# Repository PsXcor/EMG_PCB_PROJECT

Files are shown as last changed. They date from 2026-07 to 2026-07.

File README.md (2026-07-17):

# EMG PCB Project

A custom wearable electromyography (EMG) acquisition system built around the **Texas Instruments ADS1299-4** analog front end and the **Seeed Studio XIAO nRF52840**.

The project includes:

- A custom 4-layer KiCad PCB
- Arduino firmware for ADS1299 configuration and sampling
- Bluetooth Low Energy (BLE) data streaming
- A Python receiver for live plotting, diagnostics, and CSV recording
- Project-local KiCad symbols, footprints, and 3D models

> **Project status:** Active prototype development. The hardware, firmware, BLE protocol, and signal-processing workflow are still being tested and refined.

---

## Project Overview

The system measures small differential biopotential signals using the ADS1299-4, transfers samples to the XIAO nRF52840 over SPI, and sends the data wirelessly to a computer over BLE.

```text
Skin electrodes
      │
      ▼
Input protection and filtering
      │
      ▼
ADS1299-4 analog front end
      │  SPI + DRDY
      ▼
XIAO nRF52840
      │  Bluetooth Low Energy
      ▼
Python receiver
      ├── Live plot
      ├── Packet diagnostics
      └── CSV recording
```

> **Add image:** photo of the assembled PCB and battery-powered

---

## Current Capabilities

- Reads the ADS1299 device ID successfully
- Configures the ADS1299 through SPI
- Supports internal test-signal and input-short testing
- Samples at **250 samples per second**
- Currently focuses on **ADS1299 Channel 4**
- Decodes signed 24-bit two's-complement ADC samples
- Streams custom BLE notifications from the XIAO nRF52840
- Receives and plots samples in Python
- Optionally records received samples to CSV
- Tracks malformed, missing, duplicate, and out-of-order packets
- Includes project-local KiCad libraries for portability

Current development work includes:

- Reducing electrode-motion artifacts
- Investigating clipping during movement
- Improving the flexed-muscle signal-to-noise ratio
- real-time data processing
- Comparing operation with and without ADS1299 BIAS drive
- Refining packet reliability and receiver-side validation
- Developing a future Android application

---

## Repository Structure

```text
EMG_PCB_PROJECT/
├── firmware/
│   ├── emg.ble/
│   │   └── emg.ble.ino
│   └── test_ads_mcu_communication_preinstal/
│       └── test_ads_mcu_communication_preinstal.ino
│
├── python/
│   └── emg_project/
│       ├── emg_ble_receiver.py
│       ├── requirements.txt
│       └── .venv/                  
│
├── hardware/
│   └── kicad/
│       └── EMG_PCB/
│           ├── EMG_PCB.kicad_pro
│           ├── EMG_PCB.kicad_sch
│           ├── ADS1299_Section.kicad_sch
│           ├── MCU_Section.kicad_sch
│           ├── Power_Supplies.kicad_sch
│           ├── EMG_PCB.kicad_pcb
│           ├── fp-lib-table
│           ├── sym-lib-table
│           ├── lib/
│           │   ├── symbols/
│           │   ├── footprints/
│           │   └── 3d_models/
│           └── EMG_PCB_Manufacture/
│
├── .gitignore
├── .gitattributes
└── README.md
```

## Hardware

### Main Components

| Component | Purpose |
|---|---|
| ADS1299-4PAGR | Four-channel, 24-bit biopotential analog front end |
| XIAO nRF52840 | Microcontroller, SPI controller, and BLE radio |
| External 2.048 MHz clock | ADS1299 master clock |
| Li-ion battery | Portable isolated power source |
| Custom analog power supplies | Generate the required analog and digital rails |
| Input protection/filter network | Protects and filters electrode inputs |
| Electrode connector | Connects the measurement and reference electrodes |

### Main Power Rails

The PCB uses the following rails:

- `+2.5 V`
- `-2.5 V`
- `3.3 V`
- Li-ion battery input
- USB `VBUS` for development and charging

The ADS1299 analog supply and reference arrangement are implemented on the custom board. The XIAO nRF52840 provides the embedded processing and BLE connection.





---

## KiCad Design

Open the complete project using:

```text
hardware/kicad/EMG_PCB/EMG_PCB.kicad_pro
```

Do not normally open one of the child schematic files directly.

### Schematic Hierarchy

The root schematic is:

```text
EMG_PCB.kicad_sch
```

It references these hierarchical child sheets:

```text
ADS1299_Section.kicad_sch
MCU_Section.kicad_sch
Power_Supplies.kicad_sch
```

The child `.kicad_sch` files are not duplicates. Each file stores one hierarchical page used by the root schematic.

### Project-Local Libraries

Custom KiCad resources are stored in:

```text
hardware/kicad/EMG_PCB/lib/
```

This includes:

- Custom symbols
- Custom footprints
- STEP/STP 3D models
- Project library tables

Keeping these resources in the repository makes the project easier to open on another computer without losing custom parts.

### Manufacturing Files

The `EMG_PCB_Manufacture` folder contains generated Gerber and drill files. Snapshot of a specific manufactured board revision.

## Firmware

The firmware is currently developed in the Arduino IDE for the XIAO nRF52840; however, switching over to platformer.io and Cursor for serious development.

### Current Acquisition Configuration

The active configuration has included:

- 250 SPS output data rate
- Channel 4 enabled for acquisition
- Channels 1–3 powered down during single-channel testing
- 24-bit signed conversion data
- Internal square-wave test mode
- Input-short noise testing
- Optional normal electrode mode
- Experimental operation with ADS1299 BIAS disabled or enabled

Register settings may change as testing continues. The firmware source should be treated as the authoritative current configuration.

---

## BLE Data Receiver

The Python receiver is located at:

```text
python/emg_project/emg_ble_receiver.py
```

It scans for the BLE device:

```text
Nykin-EMG
```

The receiver decodes the custom BLE packet format implemented by the firmware and can:

- Plot samples live
- Print samples
- Record data to CSV
- Run for a fixed duration
- Operate without plotting
- Report packet and protocol statistics

## Development Roadmap

- [x] Design custom ADS1299/XIAO PCB
- [x] Assemble initial prototype
- [x] Verify main power rails
- [x] Read ADS1299 device ID
- [x] Capture internal test signal
- [x] Perform input-short noise testing
- [x] Stream samples over BLE
- [x] Plot and save data in Python
- [ ] Finalize safe electrode-mode register configuration
- [ ] Improve motion-artifact rejection
- [ ] Validate voltage scaling and gain calculations
- [ ] Add repeatable electrode-placement documentation
- [ ] Add digital filtering and signal-quality metrics
- [ ] Develop Android receiver application
- [ ] Complete a revised PCB based on prototype findings

---

## Author Nykin Leskiw

Developed as a personal electrical engineering and embedded-systems project

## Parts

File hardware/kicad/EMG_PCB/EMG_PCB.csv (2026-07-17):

Reference | Qty | Value | DNP | Exclude from BOM | Exclude from Board | Footprint | Datasheet
C1,C4,C5,C6,C8,C9,C10,C15,C17,C18,C21,C30,C32,C34,C36,C43,C44,C46 | 18 | 1uF |  |  |  | Capacitor_SMD:C_0603_1608Metric_Pad1.08x0.95mm_HandSolder | https://www.digikey.ca/en/products/detail/wec/GRM188R61E105KA12D/26462312
C2,C3,C7,C13,C20,C22,C24,C25,C27 | 9 | 10uF |  |  |  | Capacitor_SMD:C_0805_2012Metric_Pad1.18x1.45mm_HandSolder | https://www.digikey.ca/en/products/detail/kemet/C0805C106K8PACTU/1090830
C11 | 1 | 100uF |  |  |  | Capacitor_SMD:C_1210_3225Metric_Pad1.33x2.70mm_HandSolder | https://www.digikey.ca/en/products/detail/taiyo-yuden/LMK325BJ107MM-T/1646594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
C12,C14,C16,C19,C26,C29,C31,C38,C40,C41 | 10 | 0.1uF |  |  |  | Capacitor_SMD:C_0603_1608Metric_Pad1.08x0.95mm_HandSolder | https://www.digikey.ca/en/products/detail/kemet/C0603C104K5RAC7411/3317013
C23,C28,C35 | 3 | 2.2uF |  |  |  | Capacitor_SMD:C_0603_1608Metric_Pad1.08x0.95mm_HandSolder | https://www.digikey.ca/en/products/detail/murata-electronics/GRM185R60J225KE26D/702531
C33 | 1 | 0.01uF |  |  |  | Capacitor_SMD:C_0603_1608Metric_Pad1.08x0.95mm_HandSolder | https://www.digikey.ca/en/products/detail/kemet/C0603C103K5RAC7411/6873864
C37,C39 | 2 | 4700pF |  |  |  | Capacitor_SMD:C_0603_1608Metric_Pad1.08x0.95mm_HandSolder | https://www.digikey.ca/en/products/detail/yageo/CC0603KRX7R9BB472/302817
C42 | 1 | 1.5nF |  |  |  | Capacitor_SMD:C_0603_1608Metric_Pad1.08x0.95mm_HandSolder | https://www.digikey.ca/en/products/detail/kemet/C0603X152J4HACTU/8334437
D1 | 1 | LED |  |  |  | Diode_SMD:D_0603_1608Metric_Pad1.05x0.95mm_HandSolder | https://www.digikey.ca/en/products/detail/inolux/IN-S63AT5A/7604703
F1 | 1 | 500mA trip |  |  |  | Fuse:Fuse_0805_2012Metric_Pad1.15x1.40mm_HandSolder | https://www.digikey.ca/en/products/detail/bel-fuse-inc/0ZCK0050FF2E/4156141
H1,H2,H3 | 3 | MountingHole_Pad |  | Excluded from BOM |  | TestPoint:TestPoint_THTPad_D1.5mm_Drill0.7mm | ~
H4 | 1 | MountingHole_Pad |  | Excluded from BOM |  | ADS1299-4PAG:Untitled | ~
J1 | 1 | Conn_01x04 |  |  |  | Molex_connector:MOLEX_874370443 | https://www.digikey.ca/en/products/detail/molex/0874370443/717642?s=N4IgTCBcDaIAwA4DsAWAzEuL0gLoF8g
J2 | 1 | USB_C_Receptacle_PowerOnly_6P |  |  |  | Connector_USB:USB_C_Receptacle_HRO_TYPE-C-31-M-17 | https://www.digikey.ca/en/products/detail/gct/USB4125-GF-A-0190/14559038
J3 | 1 | Conn_01x03_Pin |  |  |  | Connector_PinHeader_2.54mm:PinHeader_1x03_P2.54mm_Vertical | ~
L1,L2,L3,L4 | 4 | 3.3 |  |  |  | Inductor_SMD:L_0805_2012Metric_Pad1.05x1.20mm_HandSolder | https://www.digikey.ca/en/products/detail/tdk/MLZ2012A3R3WT000/2465152
OSC2 | 1 | HC735-2.048MHZ |  |  |  | Oscillator:Oscillator_SMD_Abracon_ASE-4Pin_3.2x2.5mm_HandSoldering | https://www.digikey.ca/en/products/detail/cts-frequency-controls/632L3I002M04800/5228155
R1,R6 | 2 | 4.99k |  |  |  | Resistor_SMD:R_0603_1608Metric_Pad0.98x0.95mm_HandSolder | https://www.digikey.ca/en/products/detail/yageo/RC0603FR-074K99L/727219
R2 | 1 | 1M |  |  |  | Resistor_SMD:R_0603_1608Metric_Pad0.98x0.95mm_HandSolder | https://www.digikey.ca/en/products/detail/yageo/RC0603FR-071ML/726844
R3,R4,R8,R9,R10,R11 | 6 | 10k |  |  |  | Resistor_SMD:R_0603_1608Metric_Pad0.98x0.95mm_HandSolder | https://www.digikey.ca/en/products/detail/yageo/RC0603FR-0710KL/726880
R5,R12,R16 | 3 | 0k |  |  |  | Resistor_SMD:R_0603_1608Metric_Pad0.98x0.95mm_HandSolder | https://www.digikey.ca/en/products/detail/yageo/RC0603JR-070RL/726675
R7 | 1 | 1k |  |  |  | Resistor_SMD:R_0603_1608Metric_Pad0.98x0.95mm_HandSolder | https://www.digikey.ca/en/products/detail/stackpole-electronics-inc/RMCF0603FT1K00/1761077
R13 | 1 | 100k |  |  |  | Resistor_SMD:R_0603_1608Metric_Pad0.98x0.95mm_HandSolder | https://www.digikey.ca/en/products/detail/yageo/RC0603FR-07100KL/726889
R14 | 1 | 200k |  |  |  | Resistor_SMD:R_0603_1608Metric_Pad0.98x0.95mm_HandSolder | https://www.digikey.ca/en/products/detail/susumu/RG1608P-204-B-T5/1240508
R15 | 1 | 47k |  |  |  | Resistor_SMD:R_0603_1608Metric_Pad0.98x0.95mm_HandSolder | https://www.digikey.ca/en/products/detail/yageo/RC0603FR-0747KL/727253
R17,R18 | 2 | 5.1k |  |  |  | Resistor_SMD:R_0201_0603Metric_Pad0.64x0.40mm_HandSolder | https://www.digikey.ca/en/products/detail/yageo/RC0603FR-075K1L/727268
SW1 | 1 | SW_SPDT |  |  |  | ADS1299-4PAG:MHSS1105 | https://www.digikey.ca/en/products/detail/apem-inc/MHSS1105/1949465
TP1,TP5,TP6,TP10 | 4 | TestPoint |  | Excluded from BOM |  | TestPoint:TestPoint_Pad_D4.0mm | ~
TP2,TP3,TP4,TP7 | 4 | TestPoint |  | Excluded from BOM |  | TestPoint:TestPoint_Pad_D2.5mm | ~
U1 | 1 | 102010448 |  |  |  | XIAO_nRF52840:MODULE_102010448 | https://www.digikey.ca/en/products/detail/seeed-technology-co-ltd/102010448/16652893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
U2 | 1 | TPS60403DBV |  |  |  | Package_TO_SOT_SMD:SOT-23-5 | https://www.ti.com/lit/ds/symlink/tps60401.pdf
U3 | 1 | ADS1299-4PAGR |  |  |  | ADS1299-4PAG:QFP50P1200X1200X120-64N | https://www.ti.com/lit/ds/symlink/ads1299-4.pdf?HQS=dis-dk-null-digikeymode-dsf-pf-null-wwe&ts=1773509797872
U4 | 1 | TPS72325DBV |  |  |  | Package_TO_SOT_SMD:SOT-23-5 | https://www.ti.com/lit/ds/symlink/tps723.pdf
U5 | 1 | TPS73225DBVT |  |  |  | Package_TO_SOT_SMD:SOT-23-5 | https://www.digikey.ca/en/products/detail/texas-instruments/TPS73225DBVT/604395
U6 | 1 | TPS7A2033 |  |  |  | Package_TO_SOT_SMD:SOT-23-5 | https://www.digikey.ca/en/products/detail/texas-instruments/TPS7A2033PDBVR/13566866
U7,U10 | 2 | TPD2E001DZDR |  |  |  | Package_TO_SOT_SMD:SOT-143_Handsoldering | https://www.digikey.ca/en/products/detail/texas-instruments/TPD2E001DZDR/1907454
U9 | 1 | USBLC6-2SC6 |  |  |  | Package_TO_SOT_SMD:SOT-23-6 | https://www.st.com/resource/en/datasheet/usblc6-2.pdf

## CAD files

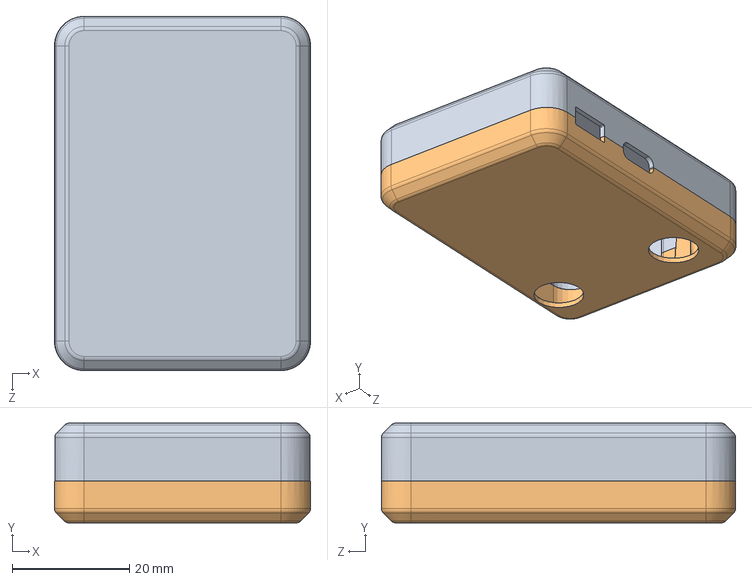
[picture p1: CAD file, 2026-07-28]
Mechanical/PCB_Case/case_asm.SLDASM
43.6 x 17.0 x 60.3 mm
enclosure_bottom
enclosure_top

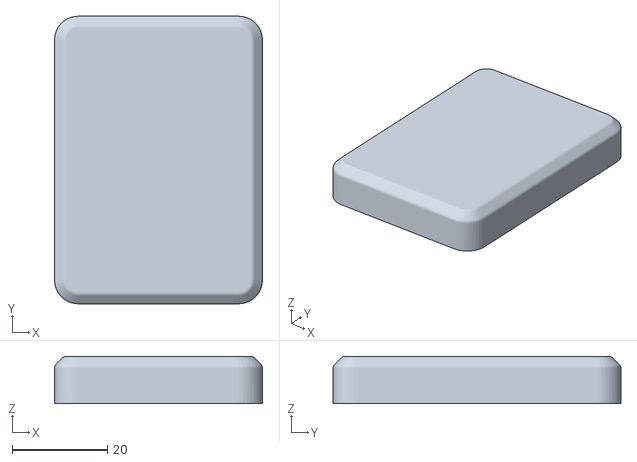
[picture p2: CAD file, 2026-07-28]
Mechanical/PCB_Case/STL_files/Print attempt1/enclosure_top.STL
43.6 x 60.3 x 9.90

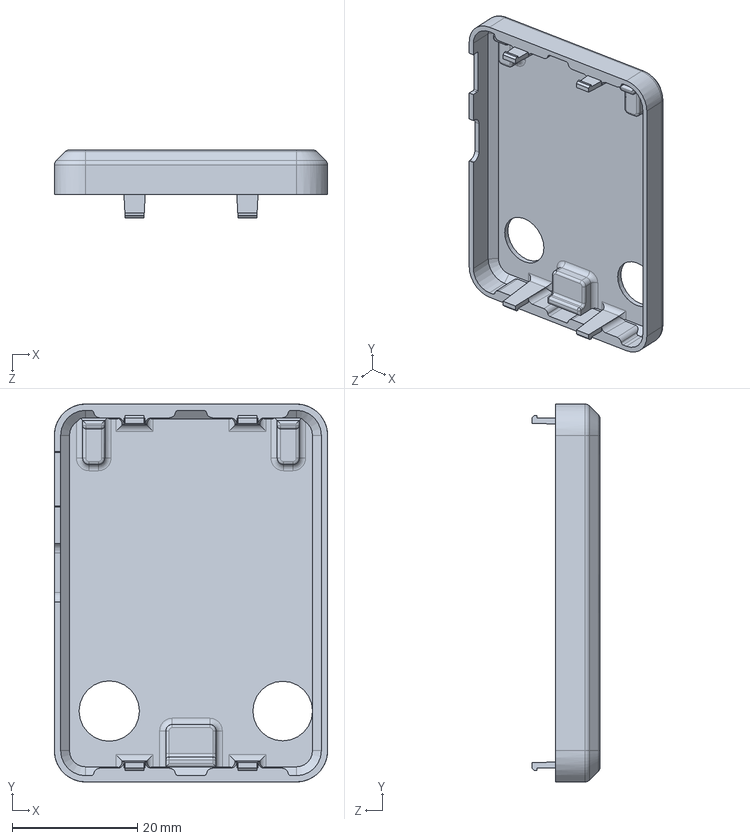
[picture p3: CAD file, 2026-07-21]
Mechanical/PCB_Case/enclosure_bottom.SLDPRT
43.6 x 60.3 x 10.9 mm

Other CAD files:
Mechanical/PCB_Case/STL_files/Print attempt1/enclosure_bottom.STL
Mechanical/PCB_Case/enclosure_master.SLDPRT
Mechanical/PCB_Case/enclosure_top.SLDPRT

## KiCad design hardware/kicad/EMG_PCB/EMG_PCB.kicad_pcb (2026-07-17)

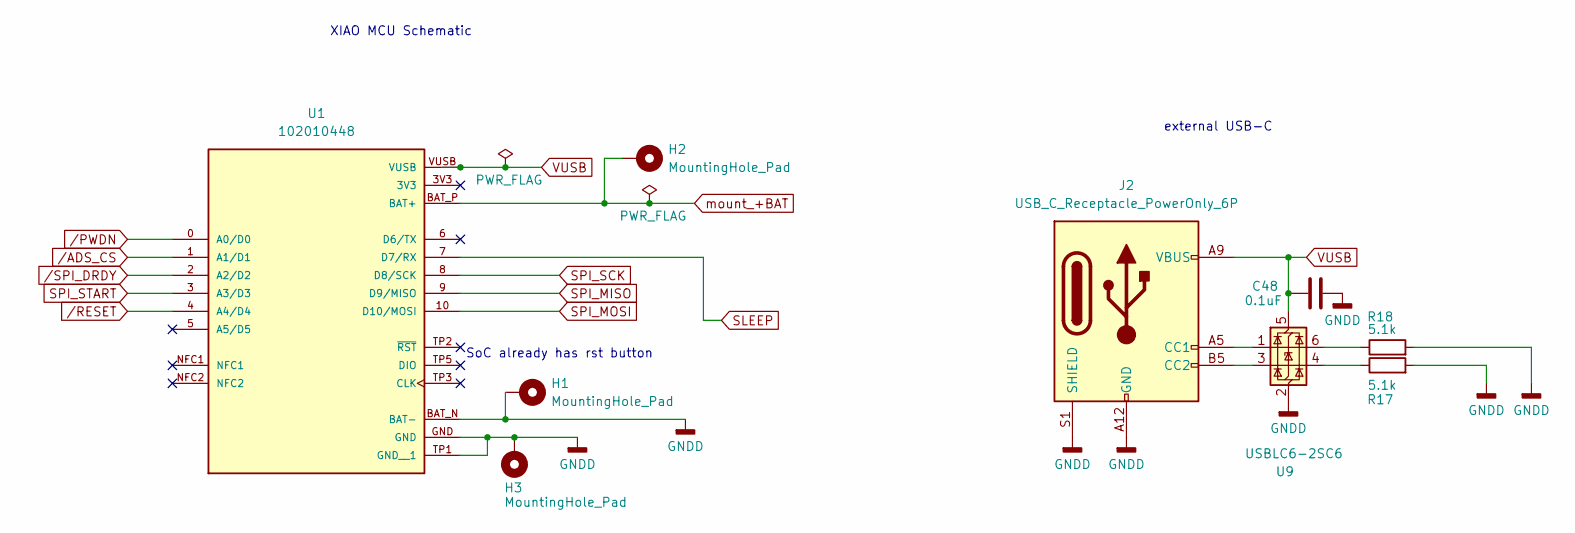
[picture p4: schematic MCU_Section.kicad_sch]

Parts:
C48: 0.1uF; C_0603_1608Metric_Pad1.08x0.95mm_HandSolder
H1, H2, H3: MountingHole_Pad; TestPoint_THTPad_D2.0mm_Drill1.0mm
J2: USB_C_Receptacle_PowerOnly_6P; USB_C_Receptacle_HRO_TYPE-C-31-M-17
R17, R18: 5.1k; R_0201_0603Metric_Pad0.64x0.40mm_HandSolder
U1: 102010448; MODULE_102010448; PARTREV 2022/08/18
U9: USBLC6-2SC6; SOT-23-6

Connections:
GNDD: C48.1, H1.1, H3.1, J2.A12 (GND), J2.B12 (GND), J2.S1 (SHIELD), R17.2, R18.2, U1.BAT_N (BAT-), U1.GND, U1.TP1 (GND__1), U9.2 (GND); also elsewhere on the board
unnamed: J2.A5 (CC1), U9.1 (I/O1)
unnamed: J2.B5 (CC2), U9.3 (I/O2)
unnamed: R17.1, U9.4 (I/O2)
unnamed: R18.1, U9.6 (I/O1)
SLEEP: U1.7 (D7/RX); also elsewhere on the board
SPI_MISO: U1.9 (D9/MISO); also elsewhere on the board
SPI_MOSI: U1.10 (D10/MOSI); also elsewhere on the board
SPI_SCK: U1.8 (D8/SCK); also elsewhere on the board
SPI_START: U1.3 (A3/D3); also elsewhere on the board
VUSB: C48.2, J2.A9 (VBUS), J2.B9 (VBUS), U1.VUSB, U9.5 (VBUS); also elsewhere on the board
mount_+BAT: H2.1, U1.BAT_P (BAT+); also elsewhere on the board
/ADS_CS: U1.1 (A1/D1); also elsewhere on the board
/PWDN: U1.0 (A0/D0); also elsewhere on the board
/RESET: U1.4 (A4/D4); also elsewhere on the board
/SPI_DRDY: U1.2 (A2/D2); also elsewhere on the board

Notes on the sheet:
SoC already has rst button
external USB-C
XIAO MCU Schematic

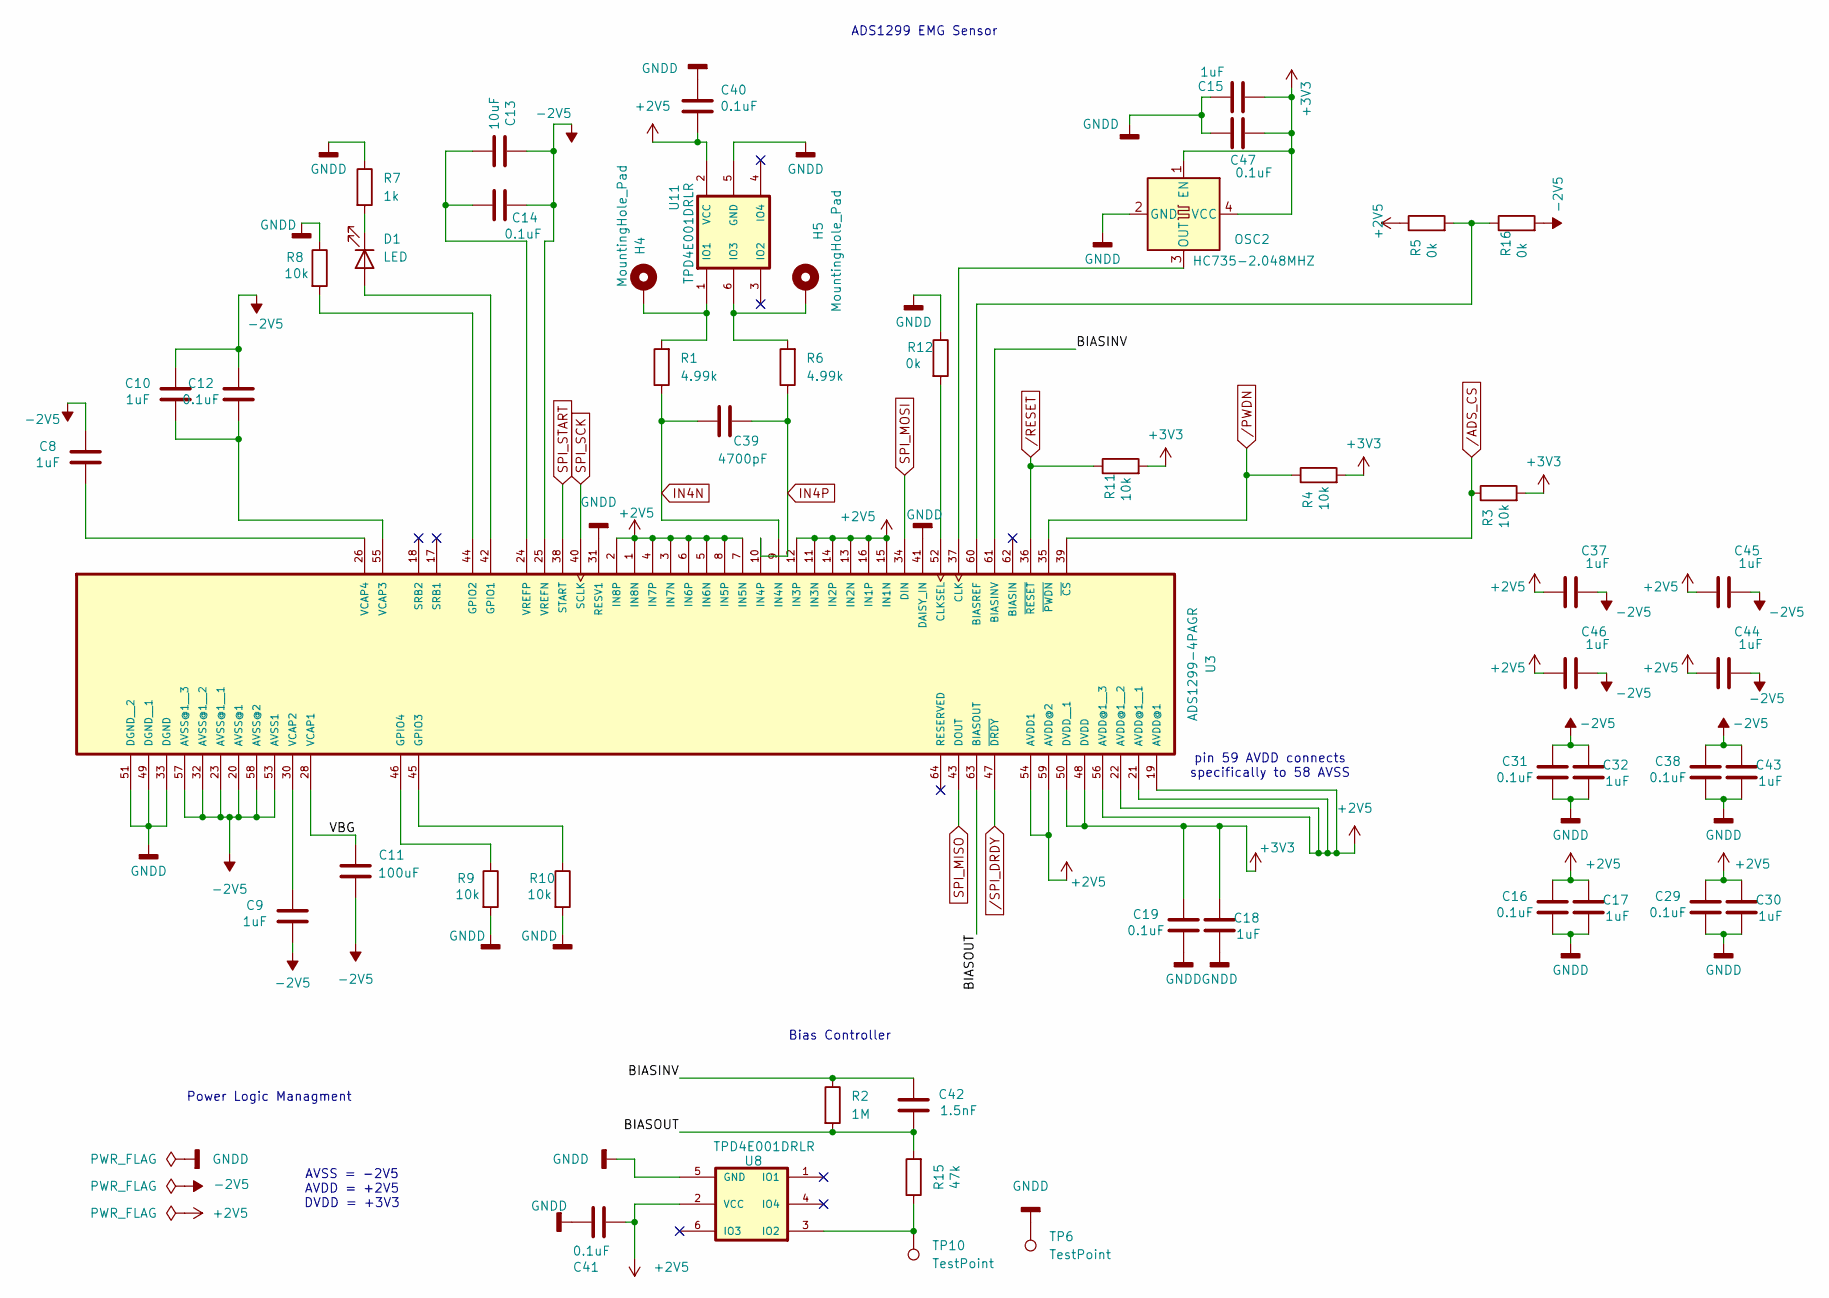
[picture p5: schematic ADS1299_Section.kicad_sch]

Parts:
C8, C9, C10, C15, C17, C18, C30, C32, C37, C43, C44, C45, C46: 1uF; C_0603_1608Metric_Pad1.08x0.95mm_HandSolder
C11: 100uF; C_1210_3225Metric_Pad1.33x2.70mm_HandSolder
C12, C14, C16, C19, C29, C31, C38, C40, C41, C47: 0.1uF; C_0603_1608Metric_Pad1.08x0.95mm_HandSolder
C13: 10uF; C_0805_2012Metric_Pad1.18x1.45mm_HandSolder
C39: 4700pF; C_0603_1608Metric_Pad1.08x0.95mm_HandSolder
C42: 1.5nF; C_0603_1608Metric_Pad1.08x0.95mm_HandSolder
D1: LED; D_0603_1608Metric_Pad1.05x0.95mm_HandSolder
H4, H5: MountingHole_Pad; Untitled
OSC2: HC735-2.048MHZ; Oscillator_SMD_Abracon_ASE-4Pin_3.2x2.5mm_HandSoldering
R1, R6: 4.99k; R_0603_1608Metric_Pad0.98x0.95mm_HandSolder
R2: 1M; R_0603_1608Metric_Pad0.98x0.95mm_HandSolder
R3, R4, R8, R9, R10, R11: 10k; R_0603_1608Metric_Pad0.98x0.95mm_HandSolder
R5, R12, R16: 0k; R_0603_1608Metric_Pad0.98x0.95mm_HandSolder
R7: 1k; R_0603_1608Metric_Pad0.98x0.95mm_HandSolder
R15: 47k; R_0603_1608Metric_Pad0.98x0.95mm_HandSolder
TP6, TP10: TestPoint; TestPoint_Pad_D4.0mm
U3: ADS1299-4PAGR; QFP50P1200X1200X120-64N
U8, U11: TPD4E001DRLR; SOT-23-6

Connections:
+2V5: C16.1, C17.1, C29.1, C30.1, C37.1, C40.2, C41.2, C44.1, C45.1, C46.1, R5.1, U3.1 (IN8N), U3.2 (IN8P), U3.3 (IN7N), U3.4 (IN7P), U3.5 (IN6N), U3.6 (IN6P), U3.7 (IN5N), U3.8 (IN5P), U3.11 (IN3N), U3.12 (IN3P), U3.13 (IN2N), U3.14 (IN2P), U3.15 (IN1N), U3.16 (IN1P), U3.19 (AVDD@1), U3.21 (AVDD@1__1), U3.22 (AVDD@1__2), U3.54 (AVDD1), U3.56 (AVDD@1__3), U3.59 (AVDD@2), U8.2 (VCC), U11.2 (VCC); also elsewhere on the board
+3V3: C15.1, C18.1, C19.1, C47.2, OSC2.1 (EN), OSC2.4 (VCC), R3.2, R4.2, R11.2, U3.48 (DVDD), U3.50 (DVDD__1); also elsewhere on the board
-2V5: C8.1, C9.2, C10.1, C11.1, C12.1, C13.1, C14.2, C31.1, C32.1, C37.2, C38.1, C43.1, C44.2, C45.2, C46.2, R16.2, U3.20 (AVSS@1), U3.23 (AVSS@1__1), U3.25 (VREFN), U3.32 (AVSS@1__2), U3.53 (AVSS1), U3.57 (AVSS@1__3), U3.58 (AVSS@2); also elsewhere on the board
/ADS1299_Section/BIASINV: C42.1, R2.1, U3.61 (BIASINV)
/ADS1299_Section/BIASOUT: C42.2, R2.2, R15.2, U3.63 (BIASOUT)
/ADS1299_Section/VBG: C11.2, U3.28 (VCAP1)
GNDD: C15.2, C16.2, C17.2, C18.2, C19.2, C29.2, C30.2, C31.2, C32.2, C38.2, C40.1, C41.1, C43.2, C47.1, OSC2.2 (GND), R7.1, R8.1, R9.2, R10.2, R12.1, TP6.1, U3.31 (RESV1), U3.33 (DGND), U3.41 (DAISY_IN), U3.49 (DGND__1), U3.51 (DGND__2), U8.5 (GND), U11.5 (GND); also elsewhere on the board
IN4N: C39.1, R1.1, U3.9 (IN4N)
IN4P: C39.2, R6.1, U3.10 (IN4P)
unnamed: D1.2 (A), U3.42 (GPIO1)
unnamed: D1.1 (K), R7.2
unnamed: OSC2.3 (OUT), U3.37 (CLK)
unnamed: R5.2, R16.1, U3.60 (BIASREF)
unnamed: R12.2, U3.52 (CLKSEL)
unnamed: R8.2, U3.44 (GPIO2)
unnamed: R10.1, U3.45 (GPIO3)
unnamed: R9.1, U3.46 (GPIO4)
unnamed: C9.1, U3.30 (VCAP2)
unnamed: C10.2, C12.2, U3.55 (VCAP3)
unnamed: C8.2, U3.26 (VCAP4)
unnamed: C13.2, C14.1, U3.24 (VREFP)
unnamed: R15.1, TP10.1, U8.3 (IO2)
unnamed: H4.1, R1.2, U11.1 (IO1)
unnamed: H5.1, R6.2, U11.6 (IO3)
SPI_MISO: U3.43 (DOUT); also elsewhere on the board
SPI_MOSI: U3.34 (DIN); also elsewhere on the board
SPI_SCK: U3.40 (SCLK); also elsewhere on the board
SPI_START: U3.38 (START); also elsewhere on the board
/ADS_CS: R3.1, U3.39 (~CS); also elsewhere on the board
/PWDN: R4.1, U3.35 (~PWDN); also elsewhere on the board
/RESET: R11.1, U3.36 (~RESET); also elsewhere on the board
/SPI_DRDY: U3.47 (~DRDY); also elsewhere on the board

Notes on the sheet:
AVSS = -2V5 AVDD = +2V5 DVDD = +3V3
Power Logic Managment
pin 59 AVDD connects specifically to 58 AVSS
Bias Controller
ADS1299 EMG Sensor

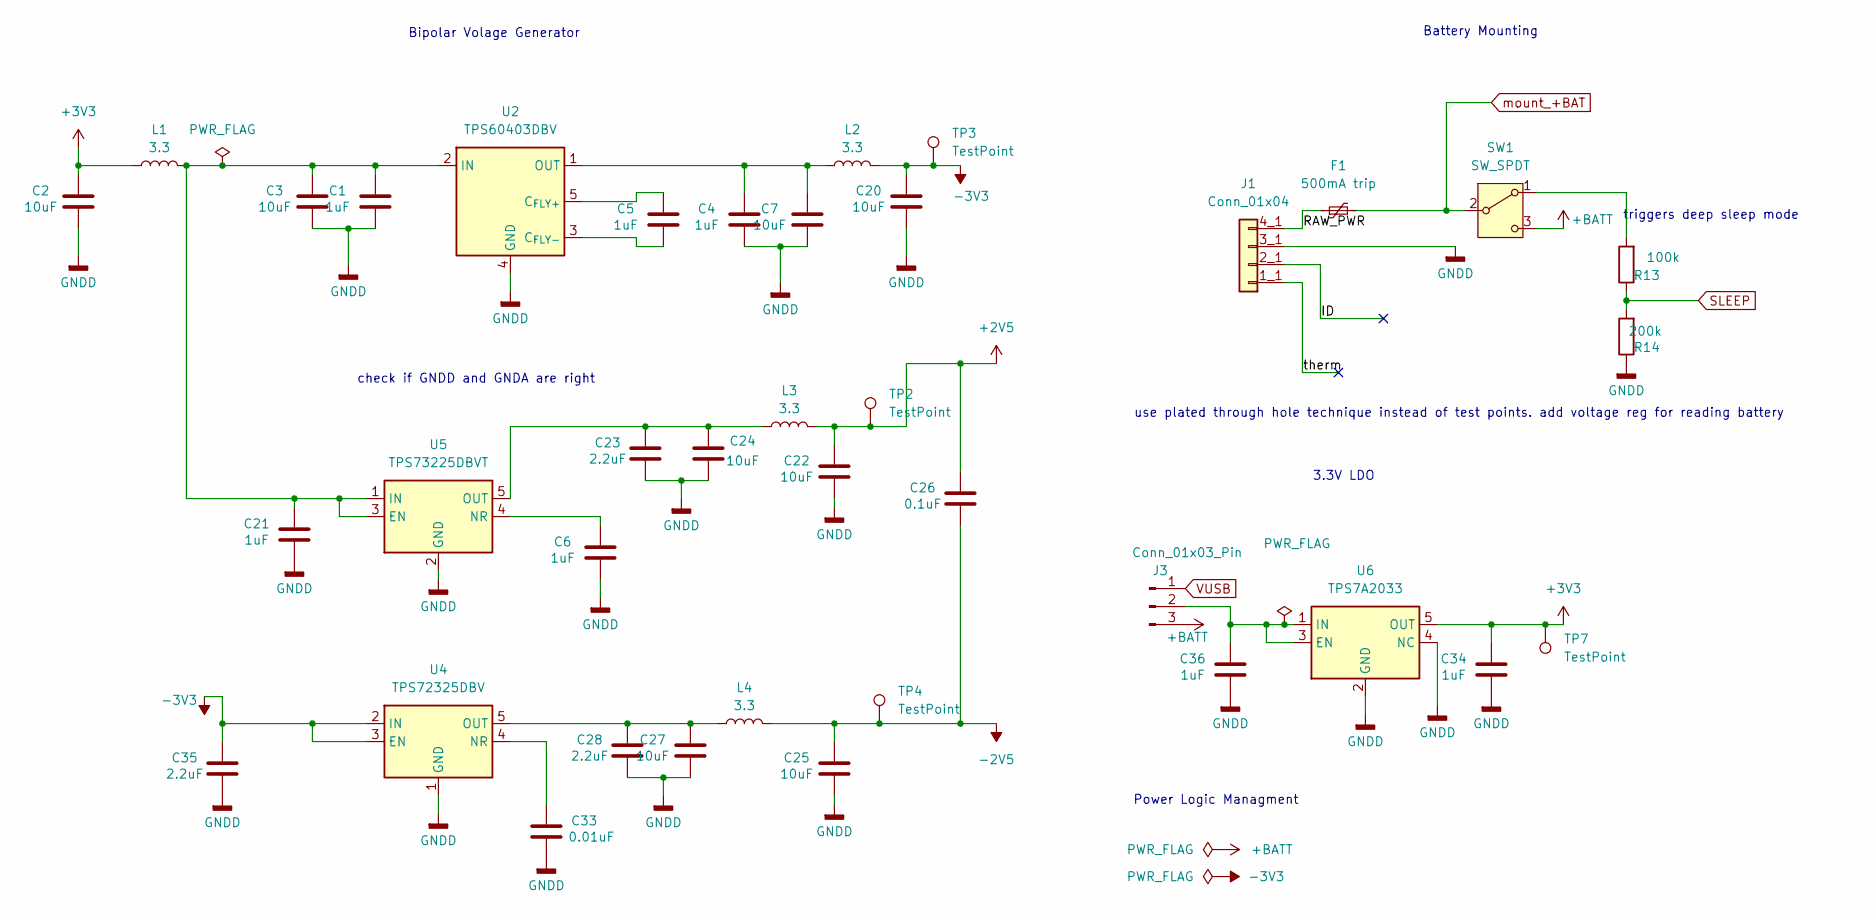
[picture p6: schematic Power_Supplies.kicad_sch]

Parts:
C1, C4, C5, C6, C21, C34, C36: 1uF; C_0603_1608Metric_Pad1.08x0.95mm_HandSolder
C2, C3, C7, C20, C22, C24, C25, C27: 10uF; C_0805_2012Metric_Pad1.18x1.45mm_HandSolder
C23, C28, C35: 2.2uF; C_0603_1608Metric_Pad1.08x0.95mm_HandSolder
C26: 0.1uF; C_0603_1608Metric_Pad1.08x0.95mm_HandSolder
C33: 0.01uF; C_0603_1608Metric_Pad1.08x0.95mm_HandSolder
F1: 500mA trip; Fuse_0805_2012Metric_Pad1.15x1.40mm_HandSolder
J1: Conn_01x04; MOLEX_874370443
J3: Conn_01x03_Pin; PinHeader_1x03_P2.54mm_Vertical
L1, L2, L3, L4: 3.3; L_0805_2012Metric_Pad1.05x1.20mm_HandSolder
R13: 100k; R_0603_1608Metric_Pad0.98x0.95mm_HandSolder
R14: 200k; R_0603_1608Metric_Pad0.98x0.95mm_HandSolder
SW1: SW_SPDT; MHSS1105
TP2, TP3, TP4, TP7: TestPoint; TestPoint_Pad_D2.5mm
U2: TPS60403DBV; SOT-23-5
U4: TPS72325DBV; SOT-23-5
U5: TPS73225DBVT; SOT-23-5
U6: TPS7A2033; SOT-23-5

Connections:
+2V5: C22.1, C26.1, L3.2, TP2.1; also elsewhere on the board
+3V3: C2.1, C34.1, L1.1, TP7.1, U6.5 (OUT); also elsewhere on the board
+BATT: J3.3, SW1.3 (C)
-2V5: C25.1, C26.2, L4.2, TP4.1; also elsewhere on the board
-3V3: C20.1, C35.1, L2.2, TP3.1, U4.2 (IN), U4.3 (EN)
/Power_Supplies/ID: J1.2_1 (ID)
/Power_Supplies/RAW_PWR: F1.1, J1.4_1 (PWR)
/Power_Supplies/therm: J1.1_1 (NTC)
GNDD: C1.2, C2.2, C3.2, C4.2, C6.2, C7.2, C20.2, C21.2, C22.2, C23.2, C24.2, C25.2, C27.2, C28.2, C33.2, C34.2, C35.2, C36.2, J1.3_1 (GND), R14.1, U2.4 (GND), U4.1 (GND), U5.2 (GND), U6.2 (GND), U6.4 (NC); also elsewhere on the board
unnamed: C36.1, J3.2, U6.1 (IN), U6.3 (EN)
unnamed: R13.2, SW1.1 (A)
unnamed: C5.1, U2.5 (C_{FLY+})
unnamed: C5.2, U2.3 (C_{FLY-})
unnamed: C1.1, C3.1, C21.1, L1.2, U2.2 (IN), U5.1 (IN), U5.3 (EN)
unnamed: C4.1, C7.1, L2.1, U2.1 (OUT)
unnamed: C33.1, U4.4 (NR)
unnamed: C27.1, C28.1, L4.1, U4.5 (OUT)
unnamed: C6.1, U5.4 (NR)
unnamed: C23.1, C24.1, L3.1, U5.5 (OUT)
SLEEP: R13.1, R14.2; also elsewhere on the board
VUSB: J3.1; also elsewhere on the board
mount_+BAT: F1.2, SW1.2 (B); also elsewhere on the board

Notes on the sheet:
check if GNDD and GNDA are right
triggers deep sleep mode
3.3V LDO
use plated through hole technique instead of test points. add voltage reg for reading battery
Power Logic Managment
Bipolar Volage Generator
Battery Mounting

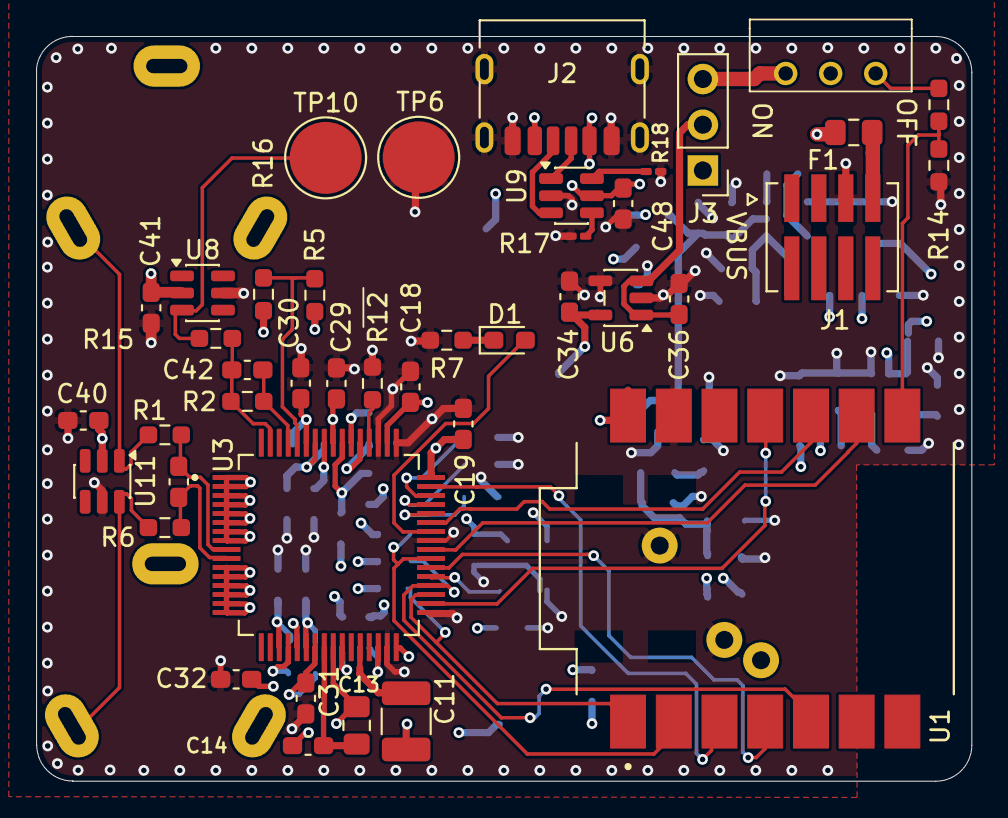
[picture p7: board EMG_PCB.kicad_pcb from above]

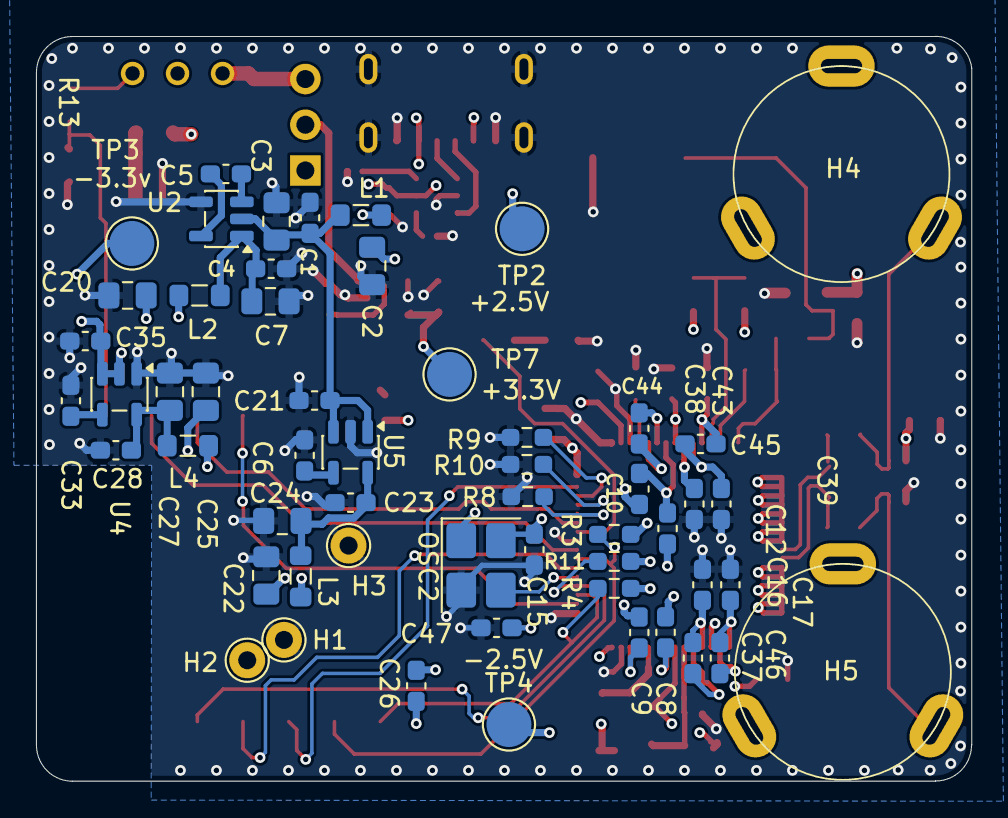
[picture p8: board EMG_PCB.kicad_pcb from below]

Board: 4 copper layers, 52.0 x 41.4 mm, 97 parts (55 on the bottom side), 52 nets.

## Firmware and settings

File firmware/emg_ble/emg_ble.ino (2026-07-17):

#include <Arduino.h>
#include <SPI.h>
#include <ArduinoBLE.h>

// Explicit declaration prevents Arduino's automatic prototype generator
// from using AdsReadResult before the type has been declared.
enum class AdsReadResult : uint8_t {
  NoData,
  ValidSample,
  InvalidFrame
};

AdsReadResult readChannel4Sample(int32_t& channel4);

/*
 * Nykin EMG: ADS1299-4 Channel 4 acquisition + BLE streaming
 *
 * Board/package assumptions:
 *   - Board: Seeed Studio XIAO nRF52840
 *   - Board package: "Seeed nRF52 mbed-enabled Boards"
 *   - Library: official ArduinoBLE library
 *
 * The application uses only fixed-size storage during normal operation.
 * ArduinoBLE itself may allocate its GATT objects internally during startup.
 *
 * Do not connect electrodes or a person during initial firmware validation.
 */

// ------------------------------------------------------------
// User-selectable compile-time settings
// ------------------------------------------------------------
constexpr bool USE_INTERNAL_SQUARE_WAVE = false;
// Used only when USE_INTERNAL_SQUARE_WAVE is false.
constexpr bool ENABLE_BIAS = false;
constexpr bool ENABLE_USB_SAMPLE_OUTPUT = true;
constexpr bool ENABLE_STREAM_DIAGNOSTICS = false;

// ------------------------------------------------------------
// General constants
// ------------------------------------------------------------
constexpr uint32_t SERIAL_BAUD_RATE = 115200;
constexpr uint16_t SAMPLE_RATE_HZ = 250;
constexpr uint8_t SAMPLES_PER_BLE_PACKET = 4;
constexpr size_t BLE_PACKET_BYTES = 20;
constexpr size_t STATUS_PACKET_BYTES = 20;
constexpr size_t RING_BUFFER_SIZE = 128;

constexpr uint32_t STATUS_UPDATE_INTERVAL_MS = 1000;
constexpr uint32_t DIAGNOSTIC_INTERVAL_MS = 5000;
constexpr uint32_t PARTIAL_PACKET_TIMEOUT_MS = 40;
constexpr uint32_t MIN_BLE_ATTEMPT_INTERVAL_US = 1000;

constexpr char BLE_DEVICE_NAME[] = "Nykin-EMG";
constexpr char BLE_SERVICE_UUID[] =
    "c91d0001-4c82-4b1f-ae27-92b8c429fc01";
constexpr char BLE_SAMPLE_CHARACTERISTIC_UUID[] =
    "c91d0002-4c82-4b1f-ae27-92b8c429fc01";
constexpr char BLE_STATUS_CHARACTERISTIC_UUID[] =
    "c91d0003-4c82-4b1f-ae27-92b8c429fc01";
constexpr uint8_t BLE_PROTOCOL_VERSION = 1;

static_assert(BLE_PACKET_BYTES ==
                  4 + (SAMPLES_PER_BLE_PACKET * sizeof(int32_t)),
              "BLE packet layout must remain exactly 20 bytes");
static_assert(RING_BUFFER_SIZE >= SAMPLES_PER_BLE_PACKET,
              "Ring buffer must hold at least one BLE packet");

// ------------------------------------------------------------
// PCB pin mapping
// ------------------------------------------------------------
constexpr uint8_t PIN_ADS_PWDN  = D0;   // XIAO -> ADS1299 pin 35
constexpr uint8_t PIN_ADS_CS    = D1;   // XIAO -> ADS1299 pin 39
constexpr uint8_t PIN_ADS_DRDY  = D2;   // ADS1299 -> XIAO, pin 47
constexpr uint8_t PIN_ADS_START = D3;   // XIAO -> ADS1299 pin 38
constexpr uint8_t PIN_ADS_RESET = D4;   // XIAO -> ADS1299 pin 36

constexpr uint8_t PIN_ADS_SCLK  = D8;   // XIAO SCK  -> ADS1299 pin 40
constexpr uint8_t PIN_ADS_DOUT  = D9;   // ADS DOUT  -> XIAO MISO
constexpr uint8_t PIN_ADS_DIN   = D10;  // XIAO MOSI -> ADS DIN

// ------------------------------------------------------------
// ADS1299 commands
// ------------------------------------------------------------
constexpr uint8_t CMD_SDATAC = 0x11;
constexpr uint8_t CMD_RDATAC = 0x10;
constexpr uint8_t CMD_RDATA  = 0x12;

// ------------------------------------------------------------
// ADS1299 registers
// ------------------------------------------------------------
constexpr uint8_t REG_ID      = 0x00;
constexpr uint8_t REG_CONFIG1 = 0x01;
constexpr uint8_t REG_CONFIG2 = 0x02;
constexpr uint8_t REG_CONFIG3 = 0x03;
constexpr uint8_t REG_LOFF    = 0x04;
constexpr uint8_t REG_CH1SET  = 0x05;
constexpr uint8_t REG_CH2SET  = 0x06;
constexpr uint8_t REG_CH3SET  = 0x07;
constexpr uint8_t REG_CH4SET  = 0x08;
constexpr uint8_t REG_BIAS_SENSP = 0x0D;
constexpr uint8_t REG_BIAS_SENSN = 0x0E;

constexpr size_t ADS1299_FRAME_BYTES = 15;

// ADS1299 requires CPOL = 0, CPHA = 1.
SPISettings adsSpiSettings(1000000, MSBFIRST, SPI_MODE1);

// ------------------------------------------------------------
// BLE GATT objects
// ------------------------------------------------------------
BLEService emgService(BLE_SERVICE_UUID);

// Fixed 20-byte value. BLERead is useful for generic BLE debugging tools;
// BLENotify is used by the Python receiver for streaming.
BLECharacteristic sampleCharacteristic(
    BLE_SAMPLE_CHARACTERISTIC_UUID,
    BLERead | BLENotify,
    BLE_PACKET_BYTES,
    true);

// Binary 20-byte status snapshot, readable by a central.
BLECharacteristic statusCharacteristic(
    BLE_STATUS_CHARACTERISTIC_UUID,
    BLERead,
    STATUS_PACKET_BYTES,
    true);

// ------------------------------------------------------------
// Fixed-size sample ring buffer
// ------------------------------------------------------------
int32_t sampleRing[RING_BUFFER_SIZE];
size_t ringHead = 0;   // next write position
size_t ringTail = 0;   // oldest sample position
size_t ringCount = 0;

// ------------------------------------------------------------
// Runtime state and diagnostics
// ------------------------------------------------------------
bool bleReady = false;
bool previousBleConnected = false;
bool previousBleSubscribed = false;

uint16_t packetSequence = 0;
uint32_t totalValidSamples = 0;
uint32_t invalidAdsFrames = 0;
uint32_t droppedSamples = 0;
uint32_t bleNotificationFailures = 0;

uint32_t lastValidSampleMillis = 0;
uint32_t lastStatusUpdateMillis = 0;
uint32_t lastDiagnosticMillis = 0;
uint32_t lastBleAttemptMicros = 0;

// DRDY is captured on its falling edge so exactly one read is requested per
// conversion. If BLE or USB work lasts longer than one 4 ms sample period,
// later edges are counted rather than allowing a partially overwritten RDATAC
// frame to appear as a large spike.
volatile bool adsSamplePending = false;
volatile uint32_t drdyInterruptCount = 0;
volatile uint32_t drdyOverrunCount = 0;

void onAdsDrdyFalling() {
  ++drdyInterruptCount;

  if (adsSamplePending) {
    ++drdyOverrunCount;
  }

  adsSamplePending = true;
}

bool claimPendingAdsSample() {
  noInterrupts();
  const bool pending = adsSamplePending;
  adsSamplePending = false;
  interrupts();
  return pending;
}

uint32_t getDrdyOverrunCount() {
  noInterrupts();
  const uint32_t value = drdyOverrunCount;
  interrupts();
  return value;
}

// ------------------------------------------------------------
// Utility functions
// ------------------------------------------------------------
void printHexByte(uint8_t value) {
  Serial.print("0x");
  if (value < 0x10) {
    Serial.print('0');
  }
  Serial.print(value, HEX);
}

void writeUint16LE(uint8_t* destination, uint16_t value) {
  destination[0] = static_cast<uint8_t>(value & 0xFFU);
  destination[1] = static_cast<uint8_t>((value >> 8) & 0xFFU);
}

void writeUint32LE(uint8_t* destination, uint32_t value) {
  destination[0] = static_cast<uint8_t>(value & 0xFFUL);
  destination[1] = static_cast<uint8_t>((value >> 8) & 0xFFUL);
  destination[2] = static_cast<uint8_t>((value >> 16) & 0xFFUL);
  destination[3] = static_cast<uint8_t>((value >> 24) & 0xFFUL);
}

void writeInt32LE(uint8_t* destination, int32_t value) {
  writeUint32LE(destination, static_cast<uint32_t>(value));
}

// ------------------------------------------------------------
// ADS1299 low-level communication
// ------------------------------------------------------------
void establishPowerUpState() {
  // Preload output states before switching pins to outputs.
  // TI recommends keeping digital inputs low while power stabilizes.
  digitalWrite(PIN_ADS_PWDN, LOW);
  digitalWrite(PIN_ADS_RESET, LOW);
  digitalWrite(PIN_ADS_START, LOW);
  digitalWrite(PIN_ADS_CS, LOW);
  digitalWrite(PIN_ADS_SCLK, LOW);
  digitalWrite(PIN_ADS_DIN, LOW);

  pinMode(PIN_ADS_PWDN, OUTPUT);
  pinMode(PIN_ADS_RESET, OUTPUT);
  pinMode(PIN_ADS_START, OUTPUT);
  pinMode(PIN_ADS_CS, OUTPUT);
  pinMode(PIN_ADS_SCLK, OUTPUT);
  pinMode(PIN_ADS_DIN, OUTPUT);

  // These are ADS1299 outputs. Never drive them from the XIAO.
  pinMode(PIN_ADS_DRDY, INPUT);
  pinMode(PIN_ADS_DOUT, INPUT);
}

void beginAdsTransaction() {
  SPI.beginTransaction(adsSpiSettings);
  digitalWrite(PIN_ADS_CS, LOW);

  // More than enough CS-to-SCLK setup time.
  delayMicroseconds(2);
}

void endAdsTransaction() {
  /*
   * TI requires at least four ADS master-clock cycles between the
   * final SCLK edge and CS rising.
   *
   * At 2.048 MHz:
   * 4 / 2.048 MHz = approximately 1.95 us.
   */
  delayMicroseconds(3);
  digitalWrite(PIN_ADS_CS, HIGH);

  // Keep CS high long enough to reset/separate transactions.
  delayMicroseconds(3);
  SPI.endTransaction();
}

void sendCommand(uint8_t command) {
  beginAdsTransaction();
  SPI.transfer(command);
  endAdsTransaction();
}

uint8_t readRegister(uint8_t address) {
  beginAdsTransaction();

  // RREG first byte: 001rrrrr
  SPI.transfer(0x20 | (address & 0x1F));
  delayMicroseconds(3);

  // Number of registers minus one: zero means read one register.
  SPI.transfer(0x00);
  delayMicroseconds(3);

  // Clock out the register value.
  const uint8_t value = SPI.transfer(0x00);
  endAdsTransaction();

  return value;
}

void writeRegister(uint8_t address, uint8_t value) {
  beginAdsTransaction();

  // WREG first byte: 010rrrrr
  SPI.transfer(0x40 | (address & 0x1F));
  delayMicroseconds(3);

  // Number of registers minus one: zero means write one register.
  SPI.transfer(0x00);
  delayMicroseconds(3);

  SPI.transfer(value);
  endAdsTransaction();
}

void wakeAndResetAds() {
  /*
   * By this point the XIAO and regulators have started.
   * Give the rails a little additional time in the all-low state.
   */
  delay(20);

  // Normal inactive state for CS.
  digitalWrite(PIN_ADS_CS, HIGH);

  // Enable the external SPI peripheral.
  SPI.begin();

  // Exit ADS power-down and release RESET.
  digitalWrite(PIN_ADS_PWDN, HIGH);
  digitalWrite(PIN_ADS_RESET, HIGH);

  /*
   * External clock is 2.048 MHz.
   * Datasheet tPOR is 2^18 clock periods = 128 ms.
   * Use 250 ms for conservative first bring-up.
   */
  delay(250);

  // Hardware reset pulse. Minimum is 2 master-clock periods.
  digitalWrite(PIN_ADS_RESET, LOW);
  delayMicroseconds(10);
  digitalWrite(PIN_ADS_RESET, HIGH);

  // Datasheet requires 18 master-clock periods after reset.
  delayMicroseconds(20);

  /*
   * The ADS1299 starts in RDATAC mode.
   * RREG and WREG are ignored until SDATAC has been sent.
   */
  sendCommand(CMD_SDATAC);
}

void normalOperation() {
  // Stop conversions while configuring.
  digitalWrite(PIN_ADS_START, LOW);

  // Ensure register commands are accepted.
  sendCommand(CMD_SDATAC);

  writeRegister(REG_CONFIG3, ENABLE_BIAS ? 0xEC : 0xE0);
  writeRegister(REG_CONFIG1, 0x96);  // Keep existing 250-SPS stream timing
  writeRegister(REG_CONFIG2, 0xC0);  // Internal test generator disabled

  writeRegister(REG_CH1SET, 0x81);   // Powered down, internally shorted
  writeRegister(REG_CH2SET, 0x81);
  writeRegister(REG_CH3SET, 0x81);
  writeRegister(REG_CH4SET, 0x50);   // Enabled, gain 12, normal electrode input

  // Channel 4 contributes to the BIAS common-mode feedback only when enabled.
  writeRegister(REG_BIAS_SENSP, ENABLE_BIAS ? 0x08 : 0x00);
  writeRegister(REG_BIAS_SENSN, ENABLE_BIAS ? 0x08 : 0x00);

  /*
   * Internal-reference startup time is specified as 150 ms.
   * Use 200 ms conservatively.
   */
  delay(200);

  // Clear any stale edge before conversions begin.
  noInterrupts();
  adsSamplePending = false;
  interrupts();

  // Start continuous conversions using the physical START pin. Keep the ADS
  // in SDATAC mode; each DRDY event is read with the RDATA command. RDATA
  // snapshots the latest completed conversion and is not corrupted if a new
  // DRDY edge occurs while the frame is being clocked out.
  digitalWrite(PIN_ADS_START, HIGH);

  Serial.print("Beginning Channel 4 normal electrode stream; BIAS ");
  Serial.println(ENABLE_BIAS ? "enabled" : "disabled");
}

void squareWaveTesting() {
  digitalWrite(PIN_ADS_START, LOW);
  sendCommand(CMD_SDATAC);

  writeRegister(REG_CONFIG3, 0xE0);  // Internal reference enabled
  writeRegister(REG_CONFIG1, 0x96);  // 250 SPS with the existing setup
  writeRegister(REG_CONFIG2, 0xD0);  // Internal test signal enabled

  writeRegister(REG_CH1SET, 0x81);
  writeRegister(REG_CH2SET, 0x81);
  writeRegister(REG_CH3SET, 0x81);
  writeRegister(REG_CH4SET, 0x05);   // Gain 1, internal test signal

  delay(200);

  noInterrupts();
  adsSamplePending = false;
  interrupts();

  // Remain in SDATAC mode and read each completed conversion with RDATA.
  digitalWrite(PIN_ADS_START, HIGH);

  Serial.println("Beginning Channel 4 internal square-wave stream (RDATA mode)");
}

int32_t signExtend24(uint8_t msb, uint8_t middle, uint8_t lsb) {
  uint32_t raw =
      (static_cast<uint32_t>(msb) << 16) |
      (static_cast<uint32_t>(middle) << 8) |
      static_cast<uint32_t>(lsb);

  // If bit 23 is set, the number is negative.
  if (raw & 0x00800000UL) {
    raw |= 0xFF000000UL;
  }

  return static_cast<int32_t>(raw);
}

AdsReadResult readChannel4Sample(int32_t& channel4) {
  // Consume at most one request for each DRDY falling edge.
  if (!claimPendingAdsSample()) {
    return AdsReadResult::NoData;
  }

  uint8_t frame[ADS1299_FRAME_BYTES];

  beginAdsTransaction();

  /*
   * Use command-based RDATA instead of RDATAC. In RDATA mode the command
   * snapshots the latest completed conversion into the output shift register.
   * TI specifies that the following read may overlap the next DRDY occurrence
   * without corrupting the frame. The byte received while sending CMD_RDATA is
   * discarded; the next 15 bytes are status + Channels 1-4.
   */
  SPI.transfer(CMD_RDATA);

  for (size_t i = 0; i < ADS1299_FRAME_BYTES; ++i) {
    frame[i] = SPI.transfer(0x00);
  }

  endAdsTransaction();

  // Preserve the existing status-byte alignment validation.
  if ((frame[0] & 0xF0) != 0xC0) {
    return AdsReadResult::InvalidFrame;
  }

  channel4 = signExtend24(frame[12], frame[13], frame[14]);
  return AdsReadResult::ValidSample;
}

void printRegister(const char* name, uint8_t address, uint8_t expected) {
  const uint8_t value = readRegister(address);

  Serial.print(name);
  Serial.print(" = ");
  printHexByte(value);

  if (value == expected) {
    Serial.println("  PASS");
  } else {
    Serial.print("  EXPECTED ");
    printHexByte(expected);
    Serial.println("  FAIL");
  }
}

// ------------------------------------------------------------
// Ring-buffer operations
// ------------------------------------------------------------
void pushSampleToRing(int32_t sample) {
  if (ringCount == RING_BUFFER_SIZE) {
    // Drop the oldest sample so the ring always contains the newest data.
    ringTail = (ringTail + 1) % RING_BUFFER_SIZE;
    --ringCount;
    ++droppedSamples;
  }

  sampleRing[ringHead] = sample;
  ringHead = (ringHead + 1) % RING_BUFFER_SIZE;
  ++ringCount;
}

int32_t peekRingSample(size_t offset) {
  const size_t index = (ringTail + offset) % RING_BUFFER_SIZE;
  return sampleRing[index];
}

void removeSamplesFromRing(size_t count) {
  if (count > ringCount) {
    count = ringCount;
  }

  ringTail = (ringTail + count) % RING_BUFFER_SIZE;
  ringCount -= count;
}

void discardBufferedSamples() {
  // Old data collected before subscription should not delay the live stream.
  droppedSamples += static_cast<uint32_t>(ringCount);
  ringTail = ringHead;
  ringCount = 0;
}

// ------------------------------------------------------------
// BLE setup and status
// ------------------------------------------------------------
void buildStatusPacket(uint8_t packet[STATUS_PACKET_BYTES]) {
  for (size_t i = 0; i < STATUS_PACKET_BYTES; ++i) {
    packet[i] = 0;
  }

  uint8_t flags = 0;
  if (bleReady) {
    flags |= 0x01;
  }
  if (bleReady && BLE.connected()) {
    flags |= 0x02;
  }
  if (bleReady && sampleCharacteristic.subscribed()) {
    flags |= 0x04;
  }
  if (USE_INTERNAL_SQUARE_WAVE) {
    flags |= 0x08;
  }

  packet[0] = BLE_PROTOCOL_VERSION;
  packet[1] = flags;
  writeUint16LE(&packet[2], SAMPLE_RATE_HZ);
  writeUint32LE(&packet[4], droppedSamples + getDrdyOverrunCount());
  writeUint32LE(&packet[8], invalidAdsFrames);
  writeUint32LE(&packet[12], totalValidSamples);
  writeUint16LE(&packet[16], static_cast<uint16_t>(ringCount));
  writeUint16LE(&packet[18], packetSequence);
}

void updateStatusCharacteristic() {
  if (!bleReady) {
    return;
  }

  uint8_t statusPacket[STATUS_PACKET_BYTES];
  buildStatusPacket(statusPacket);
  statusCharacteristic.writeValue(statusPacket, sizeof(statusPacket));
}

bool initializeBle() {
  Serial.println();
  Serial.println("BLE initialization:");

  if (!BLE.begin()) {
    Serial.println("BLE initialization result: FAIL");
    Serial.println("ADS1299 acquisition will continue without BLE.");
    return false;
  }

  BLE.setLocalName(BLE_DEVICE_NAME);
  BLE.setDeviceName(BLE_DEVICE_NAME);
  BLE.setAdvertisedService(emgService);

  emgService.addCharacteristic(sampleCharacteristic);
  emgService.addCharacteristic(statusCharacteristic);
  BLE.addService(emgService);

  uint8_t emptyPacket[BLE_PACKET_BYTES] = {0};
  emptyPacket[0] = BLE_PROTOCOL_VERSION;
  sampleCharacteristic.writeValue(emptyPacket, sizeof(emptyPacket));

  bleReady = true;
  updateStatusCharacteristic();

  if (!BLE.advertise()) {
    bleReady = false;
    Serial.println("BLE initialization result: FAIL (advertising did not start)");
    Serial.println("ADS1299 acquisition will continue without BLE.");
    return false;
  }

  Serial.println("BLE initialization result: PASS");
  Serial.print("BLE device name: ");
  Serial.println(BLE_DEVICE_NAME);
  Serial.print("Service UUID: ");
  Serial.println(BLE_SERVICE_UUID);
  Serial.print("Sample characteristic UUID: ");
  Serial.println(BLE_SAMPLE_CHARACTERISTIC_UUID);
  Serial.print("Status characteristic UUID: ");
  Serial.println(BLE_STATUS_CHARACTERISTIC_UUID);

  return true;
}

void serviceBleConnectionState() {
  if (!bleReady) {
    return;
  }

  const bool connected = BLE.connected();
  const bool subscribed = connected && sampleCharacteristic.subscribed();

  if (connected != previousBleConnected) {
    if (ENABLE_STREAM_DIAGNOSTICS && Serial) {
      Serial.println(connected ? "# BLE central connected"
                               : "# BLE central disconnected");
    }

    if (!connected) {
      // Explicitly resume advertising so another connection can be made.
      BLE.advertise();
    }
  }

  if (subscribed && !previousBleSubscribed) {
    // Begin each subscription with current data rather than a stale backlog.
    discardBufferedSamples();

    if (ENABLE_STREAM_DIAGNOSTICS && Serial) {
      Serial.println("# BLE sample notifications subscribed");
    }
  } else if (!subscribed && previousBleSubscribed) {
    if (ENABLE_STREAM_DIAGNOSTICS && Serial) {
      Serial.println("# BLE sample notifications unsubscribed");
    }
  }

  previousBleConnected = connected;
  previousBleSubscribed = subscribed;
}

// ------------------------------------------------------------
// Acquisition and BLE streaming services
// ------------------------------------------------------------
bool serviceAds1299Acquisition() {
  int32_t channel4 = 0;
  const AdsReadResult result = readChannel4Sample(channel4);

  if (result == AdsReadResult::NoData) {
    return false;
  }

  if (result == AdsReadResult::InvalidFrame) {
    ++invalidAdsFrames;
    return true;
  }

  ++totalValidSamples;
  lastValidSampleMillis = millis();
  pushSampleToRing(channel4);

  // Keep one numeric value per line for Arduino Serial Plotter.
  if (ENABLE_USB_SAMPLE_OUTPUT && Serial) {
    Serial.println(channel4);
  }

  return true;
}

void buildSamplePacket(uint8_t packet[BLE_PACKET_BYTES], uint8_t sampleCount) {
  for (size_t i = 0; i < BLE_PACKET_BYTES; ++i) {
    packet[i] = 0;
  }

  packet[0] = BLE_PROTOCOL_VERSION;
  packet[1] = sampleCount;
  writeUint16LE(&packet[2], packetSequence);

  for (uint8_t i = 0; i < sampleCount; ++i) {
    writeInt32LE(&packet[4 + (i * sizeof(int32_t))], peekRingSample(i));
  }
}
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
void loop() {
  /*
   * Read the ADS first. BLE and USB work is then performed immediately after
   * a conversion has been captured, giving almost a full 4 ms before the next
   * 250-SPS DRDY edge.
   */
  const bool handledAdsEvent = serviceAds1299Acquisition();

  static uint32_t lastBleMaintenanceMillis = 0;
  const uint32_t nowMillis = millis();

  // At normal operation this runs once per sample (every 4 ms), which is more
  // than frequent enough for ArduinoBLE. The 10 ms fallback keeps BLE alive if
  // ADS conversions stop entirely.
  if (bleReady &&
      (handledAdsEvent ||
       static_cast<uint32_t>(nowMillis - lastBleMaintenanceMillis) >= 10)) {
    lastBleMaintenanceMillis = nowMillis;
    BLE.poll();
    serviceBleConnectionState();
    serviceBleTransmission();
  }

  serviceStatusAndDiagnostics();
}

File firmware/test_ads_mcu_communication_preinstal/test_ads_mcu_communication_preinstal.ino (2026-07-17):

#include <Arduino.h>
#include <SPI.h>

/*
 * ADS1299 EMPTY-FOOTPRINT ROUTING TEST
 *
 * Board: Seeed Studio XIAO nRF52840
 *
 * IMPORTANT:
 * - ADS1299 must NOT be installed for the output/input-pull tests.
 * - Disconnect electrodes and external analog inputs.
 * - Upload using USB, then disconnect USB before powering from the
 *   battery-input bench supply.
 */

// ============================================================
// PCB pin mapping from your schematic
// ============================================================

constexpr uint8_t PIN_ADS_PWDN  = D0;   // XIAO D0 -> ADS1299 pin 35
constexpr uint8_t PIN_ADS_CS    = D1;   // XIAO D1 -> ADS1299 pin 39
constexpr uint8_t PIN_ADS_DRDY  = D2;   // XIAO D2 <- ADS1299 pin 47
constexpr uint8_t PIN_ADS_START = D3;   // XIAO D3 -> ADS1299 pin 38
constexpr uint8_t PIN_ADS_RESET = D4;   // XIAO D4 -> ADS1299 pin 36

// D7 is labelled SLEEP on your XIAO sheet, but its destination is not
// shown in the ADS1299 schematic. This code deliberately does not drive it.

constexpr uint8_t PIN_ADS_SCLK  = D8;   // XIAO D8 -> ADS1299 pin 40
constexpr uint8_t PIN_ADS_DOUT  = D9;   // XIAO D9 <- ADS1299 pin 43
constexpr uint8_t PIN_ADS_DIN   = D10;  // XIAO D10 -> ADS1299 pin 34

// ============================================================
// Choose ONE test, upload, and probe the associated pad
// ============================================================

enum TestMode : uint8_t {
  TEST_ALL_LOW       = 0,
  TEST_PWDN_TOGGLE   = 1,
  TEST_CS_TOGGLE     = 2,
  TEST_START_TOGGLE  = 3,
  TEST_RESET_TOGGLE  = 4,
  TEST_DRDY_TRACE    = 5,
  TEST_DOUT_TRACE    = 6,
  TEST_SPI_BURST     = 7,
  TEST_OPERATING_IDLE = 8
};

// Change only this line:
constexpr TestMode TEST_MODE = TEST_SPI_BURST;

// ADS1299 uses SPI mode 1:
// CPOL = 0, CPHA = 1.
// Start conservatively at 1 MHz.
SPISettings adsSpiSettings(1000000, MSBFIRST, SPI_MODE1);

// ============================================================
// Basic pin-state functions
// ============================================================

void configureOutputs() {
  pinMode(PIN_ADS_PWDN, OUTPUT);
  pinMode(PIN_ADS_CS, OUTPUT);
  pinMode(PIN_ADS_START, OUTPUT);
  pinMode(PIN_ADS_RESET, OUTPUT);
  pinMode(PIN_ADS_SCLK, OUTPUT);
  pinMode(PIN_ADS_DIN, OUTPUT);

  // These are ADS1299 outputs and must remain nRF inputs.
  pinMode(PIN_ADS_DRDY, INPUT);
  pinMode(PIN_ADS_DOUT, INPUT);
}

void setAllLow() {
  SPI.end();
  configureOutputs();

  digitalWrite(PIN_ADS_PWDN, LOW);
  digitalWrite(PIN_ADS_CS, LOW);
  digitalWrite(PIN_ADS_START, LOW);
  digitalWrite(PIN_ADS_RESET, LOW);
  digitalWrite(PIN_ADS_SCLK, LOW);
  digitalWrite(PIN_ADS_DIN, LOW);
}

void setOperatingIdle() {
  SPI.end();
  configureOutputs();

  // Normal inactive/idle state after supplies have stabilized.
  digitalWrite(PIN_ADS_PWDN, HIGH);   // ADS active
  digitalWrite(PIN_ADS_RESET, HIGH);  // not held in reset
  digitalWrite(PIN_ADS_START, LOW);   // conversions stopped
  digitalWrite(PIN_ADS_CS, HIGH);     // SPI deselected
  digitalWrite(PIN_ADS_SCLK, LOW);    // mode-1 clock idles low
  digitalWrite(PIN_ADS_DIN, LOW);     // quiet MOSI

  pinMode(PIN_ADS_DRDY, INPUT);
  pinMode(PIN_ADS_DOUT, INPUT);
}

void togglePin(uint8_t pin) {
  digitalWrite(pin, LOW);
  delay(500);

  digitalWrite(pin, HIGH);
  delay(500);
}

/*
 * DOUT and DRDY are normally outputs from the ADS1299.
 *
 * Since the ADS is currently missing, these traces would otherwise float.
 * Alternating the nRF's internal pull-down and pull-up lets you confirm
 * continuity from the nRF all the way to the empty ADS pad.
 */
void inputTraceTest(uint8_t pin) {
  pinMode(pin, INPUT_PULLDOWN);
  delay(2000);

  pinMode(pin, INPUT_PULLUP);
  delay(2000);
}

void sendSpiTestBurst() {
  /*
   * Valid ADS1299-style sequence:
   *
   * 0x11 = SDATAC
   * 0x20 = RREG starting at register 0x00
   * 0x00 = read one register
   * 0x00 = dummy byte to generate readback clocks
   *
   * With the ADS absent, there will be no valid MISO response.
   */

  SPI.beginTransaction(adsSpiSettings);

  digitalWrite(PIN_ADS_CS, LOW);
  delayMicroseconds(10);

  SPI.transfer(0x11);  // SDATAC
  delayMicroseconds(10);

  SPI.transfer(0x20);  // RREG ID
  SPI.transfer(0x00);  // one register
  delayMicroseconds(10);

  SPI.transfer(0x00);  // dummy clocks

  // ADS1299 requires at least four master-clock periods before CS rises.
  delayMicroseconds(10);

  digitalWrite(PIN_ADS_CS, HIGH);
  SPI.endTransaction();
}

void setup() {
  // No Serial wait, so the test runs from battery/bench power without USB.

  switch (TEST_MODE) {
    case TEST_ALL_LOW:
      setAllLow();
      break;

    case TEST_PWDN_TOGGLE:
    case TEST_CS_TOGGLE:
    case TEST_START_TOGGLE:
    case TEST_RESET_TOGGLE:
      setOperatingIdle();
      break;

    case TEST_DRDY_TRACE:
    case TEST_DOUT_TRACE:
      setOperatingIdle();
      break;

    case TEST_SPI_BURST:
      setOperatingIdle();

      // Hardware SPI uses D8/D9/D10 on the XIAO.
      SPI.begin();

      pinMode(PIN_ADS_CS, OUTPUT);
      digitalWrite(PIN_ADS_CS, HIGH);

      pinMode(PIN_ADS_PWDN, OUTPUT);
      pinMode(PIN_ADS_RESET, OUTPUT);
      pinMode(PIN_ADS_START, OUTPUT);

      digitalWrite(PIN_ADS_PWDN, HIGH);
      digitalWrite(PIN_ADS_RESET, HIGH);
      digitalWrite(PIN_ADS_START, LOW);
      break;

    case TEST_OPERATING_IDLE:
      setOperatingIdle();
      break;
  }
}

void loop() {
  switch (TEST_MODE) {
    case TEST_ALL_LOW:
      // Hold continuously.
      delay(1000);
      break;

    case TEST_PWDN_TOGGLE:
      togglePin(PIN_ADS_PWDN);
      break;

    case TEST_CS_TOGGLE:
      togglePin(PIN_ADS_CS);
      break;

    case TEST_START_TOGGLE:
      togglePin(PIN_ADS_START);
      break;

    case TEST_RESET_TOGGLE:
      togglePin(PIN_ADS_RESET);
      break;

    case TEST_DRDY_TRACE:
      inputTraceTest(PIN_ADS_DRDY);
      break;

    case TEST_DOUT_TRACE:
      inputTraceTest(PIN_ADS_DOUT);
      break;

    case TEST_SPI_BURST:
      sendSpiTestBurst();
      delay(500);
      break;

    case TEST_OPERATING_IDLE:
      delay(1000);
      break;
  }
}

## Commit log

2026-07-17 Add Arduino firmware and Python BLE receiver
2026-07-17 Add KiCad schematic and PCB design
    [ADS1299_Section.kicad_sch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]
2026-07-19 first attempt of filtering
2026-07-21 added mechanical folder with enclosure design
    [Bottom_enclosure.SLDPRT, Top_enclosure.SLDPRT, case_asm.SLDASM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]
2026-07-21 enclosure v1 with hooks
    [Bottom_enclosure.SLDPRT, Top_enclosure.SLDPRT, case_asm.SLDASM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]
2026-07-28 changes to filtering
    [case_asm.SLDASM, enclosure_bottom.STL, enclosure_top.STL]
2026-07-28 reverted to old filtering code
